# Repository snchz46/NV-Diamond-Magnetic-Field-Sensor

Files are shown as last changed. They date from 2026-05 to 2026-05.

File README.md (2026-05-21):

# NV-Center Optical Readout System — Fraunhofer IAO

> Hardware and firmware platform for Nitrogen-Vacancy (NV) center-based optical sensing.
> Acquires photon-count signals from NV-center diamond samples, applies quenching pulses,
> and streams live data via a browser dashboard hosted on an ESP32-S3.




---

## System at a glance

<p align="left">
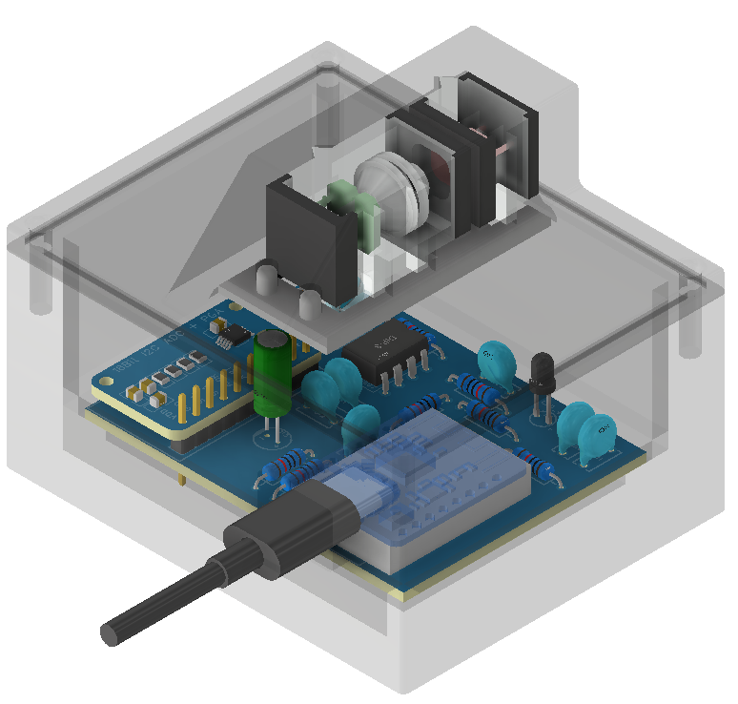
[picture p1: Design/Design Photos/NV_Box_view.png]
  
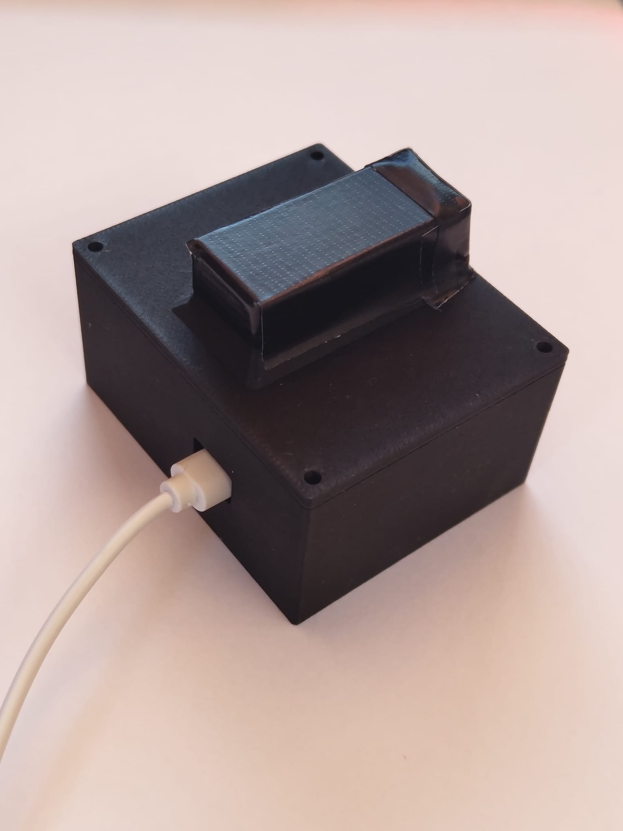
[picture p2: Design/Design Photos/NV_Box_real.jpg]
  
</p>

<!-- PLACEHOLDER: animated GIF or short demo video link
<p align="center">
  <a href="https://YOUR_VIDEO_LINK">
    <img src=""Design/Design Photos/web_dashboard_preview.gif" alt="Web dashboard demo" width="600"/>
  </a>
</p>
-->

<p align="left">
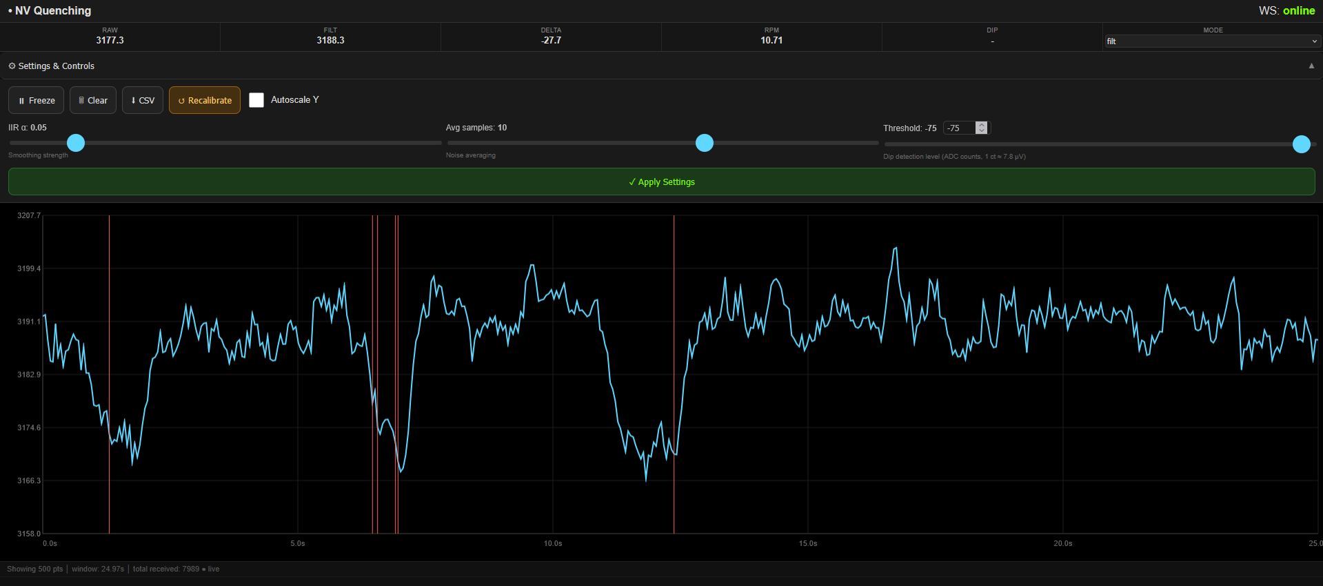
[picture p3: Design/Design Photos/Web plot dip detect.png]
ADC signal plot
  
</p>

---

## Module gallery

| NV Module | Optical Module | Quenching PCB |
|:---:|:---:|:---:|
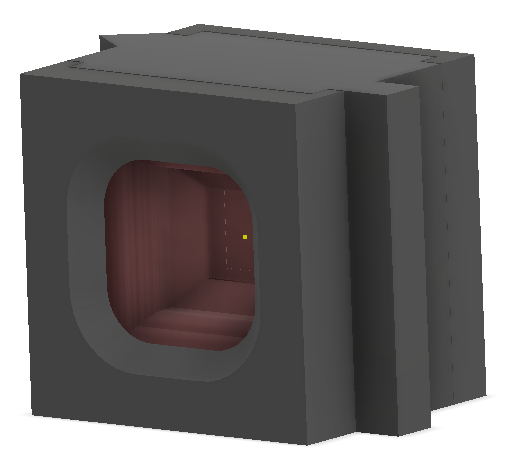
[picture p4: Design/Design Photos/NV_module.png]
NV Module
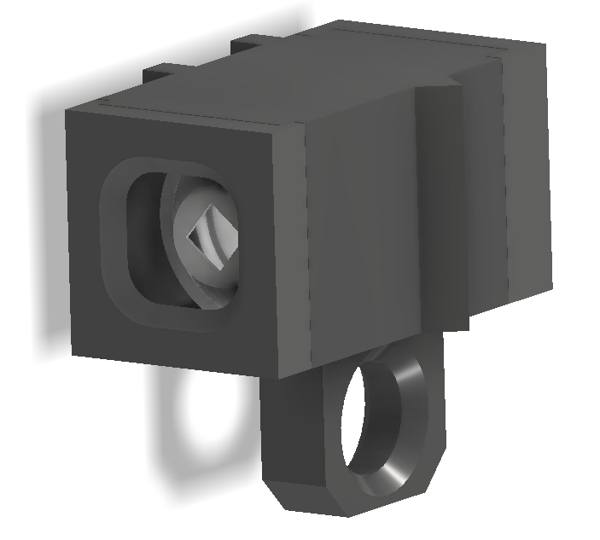
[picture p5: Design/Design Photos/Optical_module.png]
Optical Module
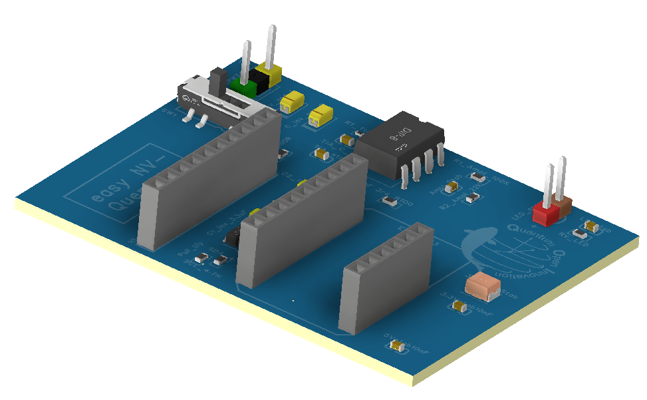
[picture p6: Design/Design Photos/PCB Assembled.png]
PCB
|  |  |  |
| Diamond sample holder | BPW34 photodetector | Rev-5 quenching board |

---

## Hardware overview

| Module | Description | Photo |
| --- | --- | ----- |
| **NV Module** | Diamond sample holder with optical coupling | <!-- PLACEHOLDER: `![](Design Photos/NV_module.png)` --> |
| **Optical Module** | BPW34 photodetector with signal conditioning | <!-- PLACEHOLDER: `![](Design Photos/Optical_module.png)` --> |
| **Quenching PCB (rev 5)** | Laser/MW pulse driver for spin initialization | <!-- PLACEHOLDER: `![](Design Photos/PCB Assembled.png)` --> |
| **Readout Box** | Enclosure integrating all modules | <!-- PLACEHOLDER: `![](Design Photos/NV_Box.png)` --> |
| **ESP32-S3** | Main MCU — ADC readout + Wi-Fi web server | |
| **ADS1015 / ADS1115** | External 12/16-bit ADC for precision readout | |

---

## Schematic

<p align="left">
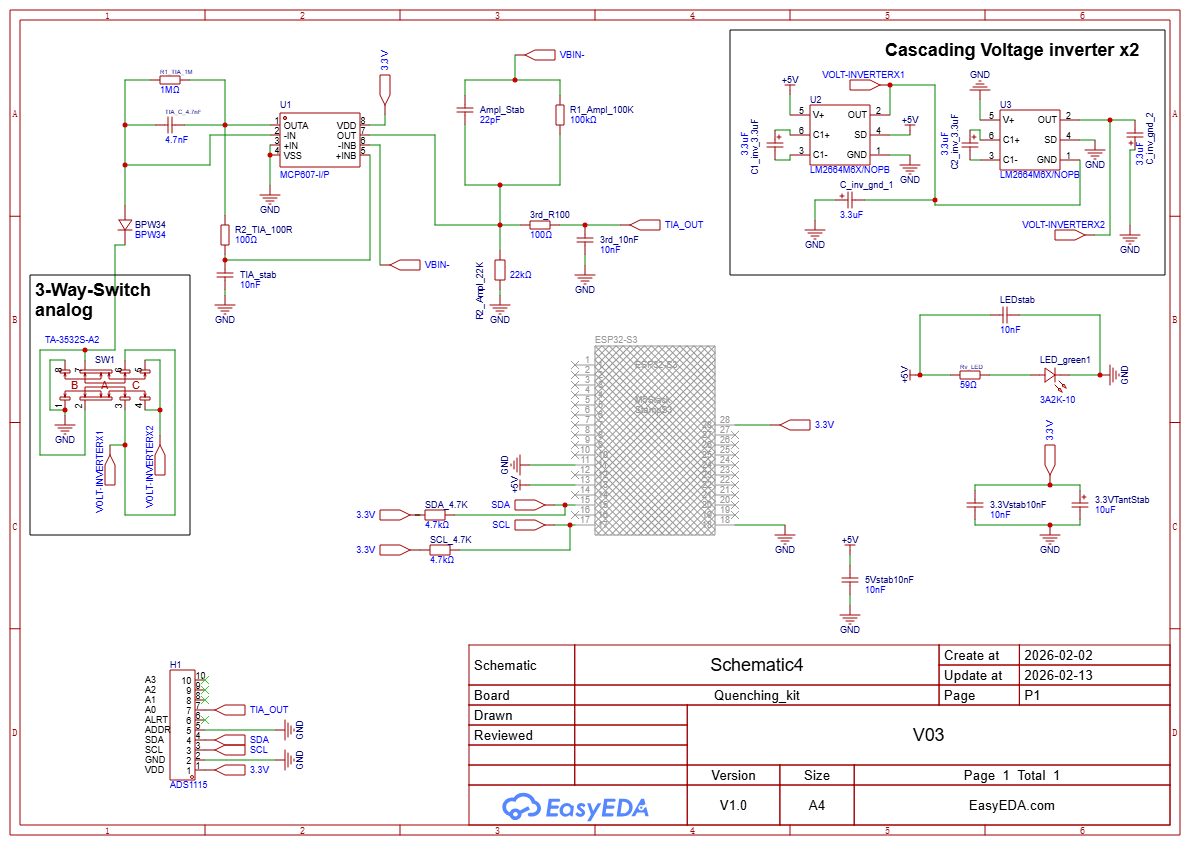
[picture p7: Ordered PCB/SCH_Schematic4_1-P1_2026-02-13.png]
Schematic rev 5
  
</p>

Full schematic PDF → [`SCH_Schematic4_2026-02-13.pdf`](Ordered%20PCB/SCH_Schematic4_2026-02-13.pdf)

---

## Performance results

| Metric | Value | Conditions |
| --- | ----- | --- |
| ADC noise floor | ___ LSB RMS | ADS1115, PGA ±0.256 V |
| Sampling rate | ___ Hz | Web server mode |
| Signal-to-noise ratio | ___ dB | Laser power: ___ mW |
| Quenching pulse width | ___ µs | |
| Web dashboard latency | ___ ms | LAN, single client |

<p align="left">
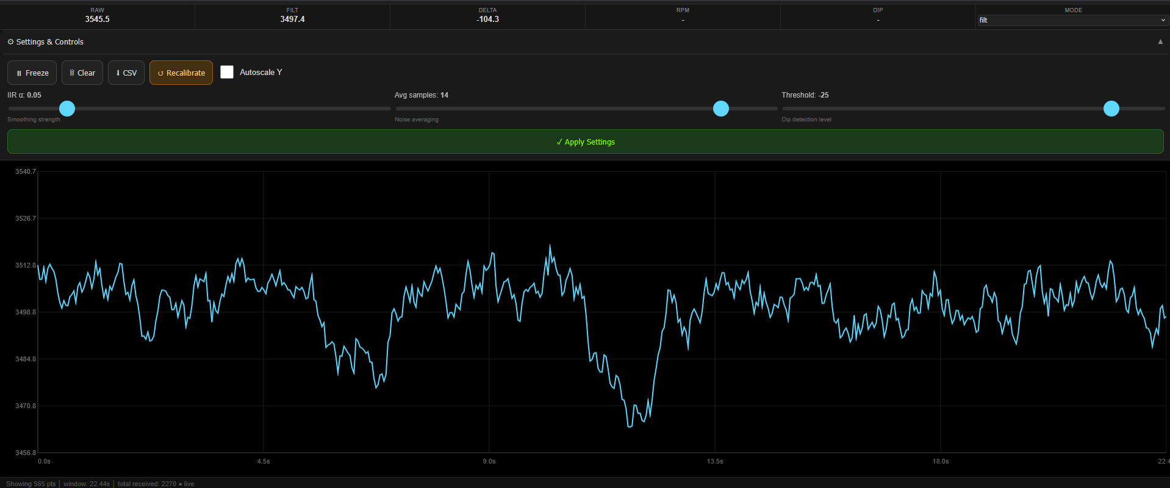
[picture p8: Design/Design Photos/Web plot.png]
Signal comparison
  
  <br><em>Figure 1 — Raw vs. optimized ADC readout (ADD CAPTION)</em>
</p>

---

## Assembly walkthrough

|  |  |
| - | - |
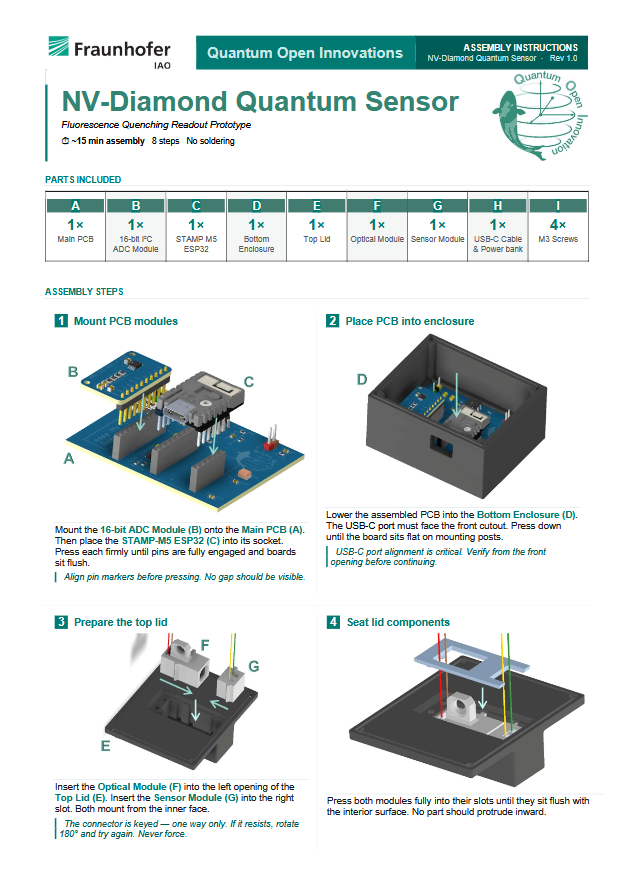
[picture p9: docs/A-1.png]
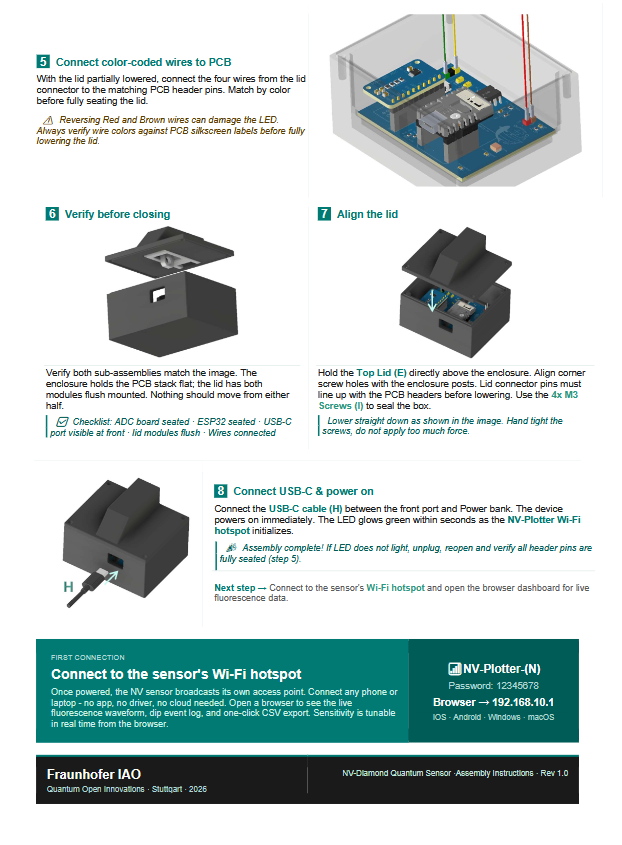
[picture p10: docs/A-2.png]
|  |  |

---

## Web dashboard

<p align="left">
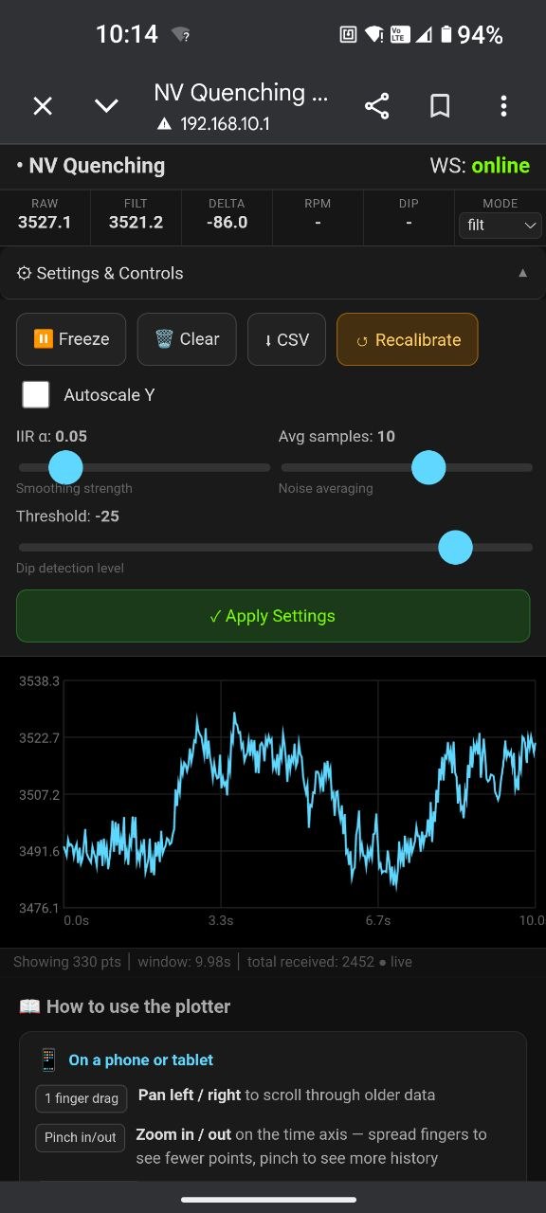
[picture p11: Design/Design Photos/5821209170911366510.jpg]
Live web dashboard
  
  <br><em>Live ADC readout served from ESP32-S3 over Wi-Fi</em>
</p>

After flashing, the ESP32 hosts a dashboard at the IP shown on the serial monitor:

- Live ADC signal plot
- Start / Stop acquisition
- CSV data export

---

## 3D model

<p align="left">
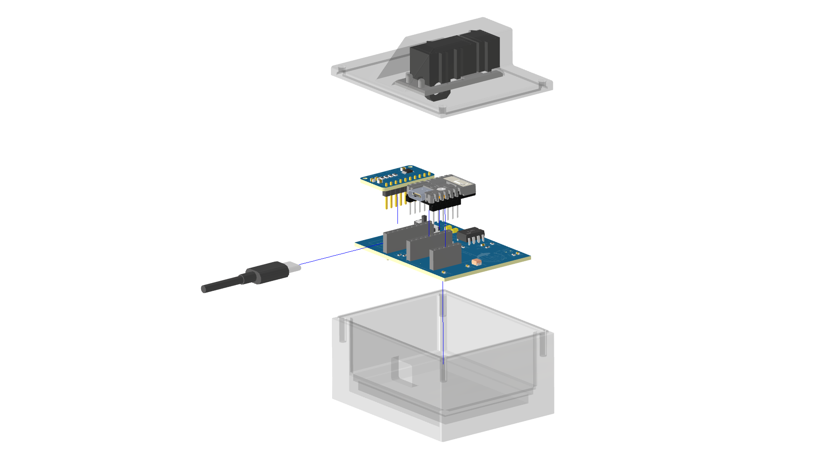
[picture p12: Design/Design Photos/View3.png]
3D assembly
  
</p>

CAD files: Autodesk Inventor assemblies in `Design/`. Printable STLs in `Design/Print/`.

---

## Project structure

```text
Fraunhofer/
├── Design/                        # Mechanical CAD (Autodesk Inventor)
│   ├── Parts/                     # Component libraries (PCB 3D models, connectors, sensors)
│   ├── Photos/                    # Renders and assembly photos
│   ├── Print/                     # 3D-printable STL exports
│   ├── Assembly_NV_Module.iam     # NV sensor module assembly
│   ├── Assembly_Optical_Module.iam
│   ├── Assembly_Quenching.iam
│   └── Assembly_Box.iam           # Enclosure assembly
│
├── Design Photos/                 # Step-by-step build photos and design plots
│
├── ESP32/                         # Firmware (PlatformIO / Arduino)
│   └── ReadOut/
│       ├── ESP32S3 ReadOut/                       # Base acquisition firmware
│       ├── ESP32S3 ReadOut Web Server/            # Web interface variant
│       ├── ESP32S3 ReadOut Web Server Optimized/  # Production variant
│       └── ESP32S3 Noise Optimization/            # ADC noise experiments
│
└── Ordered PCB/                   # Manufacturing files — PCB revision 5
    ├── Gerber_PCB5_2026-02-13.zip
    ├── BOM_Quenching_kit_PCB5_2026-02-13.xlsx
    ├── PickAndPlace_PCB5_2026-02-13.xlsx
    └── SCH_Schematic4_2026-02-13.pdf
```

---

## Firmware

Built with **PlatformIO** (Arduino framework).

```bash
cd "ESP32/ReadOut/ESP32S3 ReadOut Web Server Optimized"
pio run --target upload
```

---

## PCB manufacturing (rev 5)

| File | Purpose |
| ---- | --- |
| `Gerber_PCB5_2026-02-13.zip` | Upload to JLCPCB / PCBWay |
| `BOM_Quenching_kit_PCB5_2026-02-13.xlsx` | Bill of materials |
| `PickAndPlace_PCB5_2026-02-13.xlsx` | SMT assembly file |
| `SCH_Schematic4_2026-02-13.pdf` | Full schematic |
| `3D_PCB5.step` | 3D PCB model |

---

## Dependencies

| Tool | Version |
| ---- | --- |
| Autodesk Inventor | 2024+ |
| PlatformIO | Latest (VS Code extension) |
| EasyEDA | v6.5.51 |
| ESP32 Arduino core | Latest stable |

---

## Authors

Samuel Sanchez Moreno — Fraunhofer IAO (HiWi, 2025–2026)

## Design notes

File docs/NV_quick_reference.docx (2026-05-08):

NV Quenching Readout System

Quick Reference — Firmware & Software

Samuel Sanchez | Fraunhofer IAO, Quantum Open Innovations | 2025

# At a Glance

16-bit ADC resolution | 7.8 µV/LSB At GAIN_SIXTEEN | 0.34 mV RMS System noise | 2–3 % Quench amplitude

~86 Hz Step rate | ~22 Hz WebSocket rate | ~91 s CSV buffer | < 20 € Total BOM cost

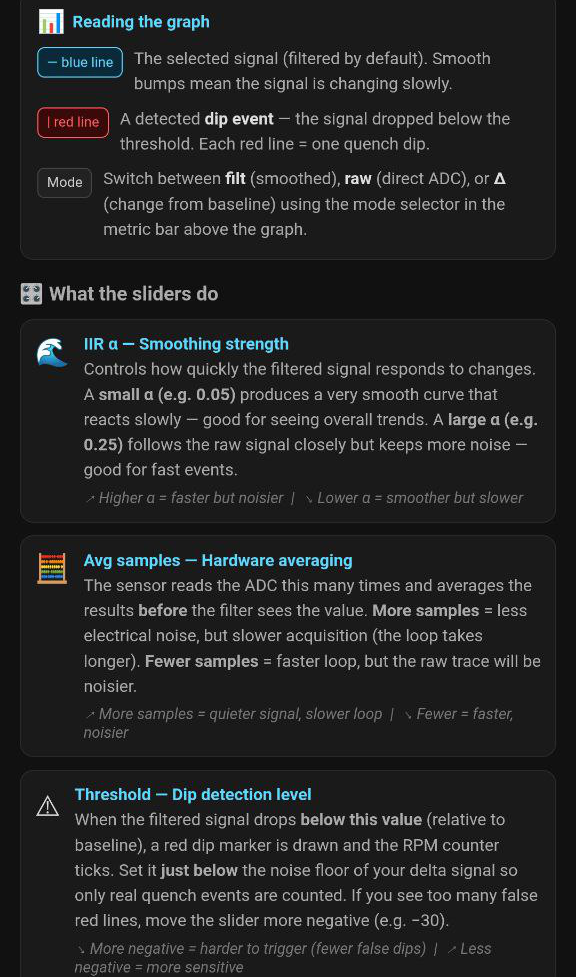
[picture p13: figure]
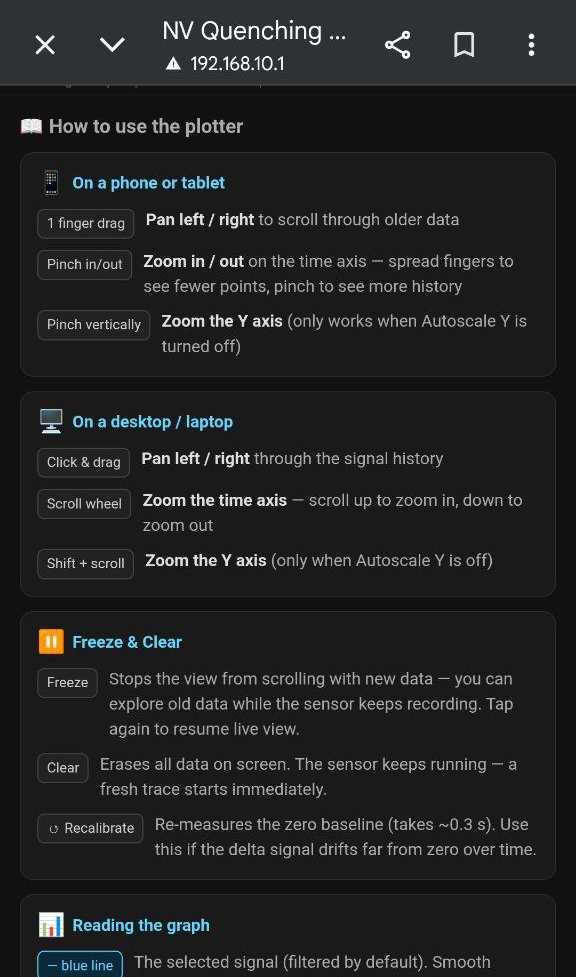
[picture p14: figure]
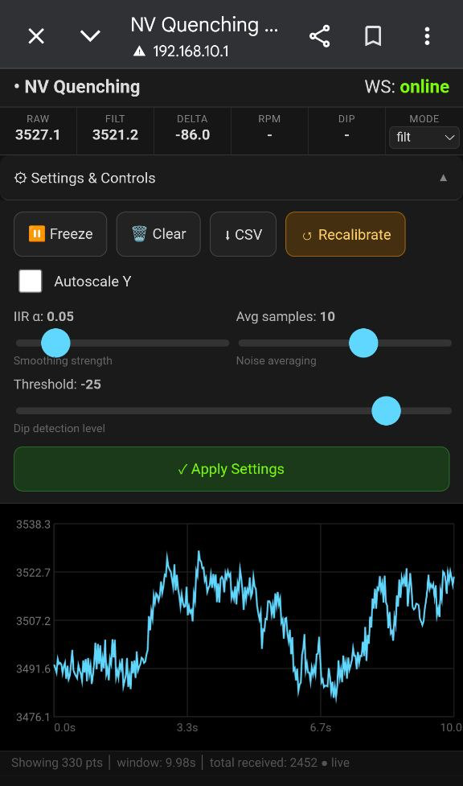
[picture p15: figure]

Figure 1 Live interface with built in settings panel and usage guide

# System Overview

Hardware chain - BPW34 photodiode — light-to-current - MCP607 TIA — Rf = 1 MΩ, 0–1 V output - RC filter — 2-stage, fc ≈ 160 kHz - ADS1115 — 16-bit I²C ADC, 860 SPS - ESP32-S3 — M5 Stamp S3, Wi-Fi AP Connectivity - Wi-Fi AP — SSID: NV-Plotter-N - IP — 192.168.10.1 - mDNS — http://nv-plotter.local - HTTP :80 — browser app + CSV export - WebSocket :81 — live data + config | Signal path - Average N fresh ADC reads - Display IIR filter — slow (α configurable) - Detection IIR filter — fast (α = 0.50, fixed) - Baseline subtraction — delta = filtered − baseline - Hysteresis comparator — entry + 50 ms guard - Dip latch — accumulates over 4-step window - Publish JSON — ~22 Hz to all WS clients - CSV ring buffer — 2000 entries, ~91 s Firmware modules - nv_signal — ADC, filters, dip, RPM - csv_logger — buffer + HTTP export - web_ui — AP, HTTP, WebSocket - web_page — full browser app (PROGMEM) - main — loop, decimation, latch

# System Performance

Parameter | Value | Notes
ADC resolution | 16-bit (7.8 µV/LSB) | GAIN_SIXTEEN, ±0.256 V FS
Noise single read | ~2 LSB RMS ≈ 15.6 µV | ADS1115 datasheet at 860 SPS
Noise avg = 10 | ~0.6 LSB RMS ≈ 4.7 µV | √10 improvement
System noise (measured) | 0.34 mV RMS | At TIA output
Baseline signal level | 0.80–1.00 V | 525-532 nm LED, BPW34, Rf = 1 MΩ
Quench dip amplitude | 15–30 mV (2–3%) | 1920-3840 ADC counts
Display filter −3 dB | ~0.69 Hz | α = 0.05, ~86 steps/s
Detection filter −3 dB | ~21 Hz | α = 0.50, ~86 steps/s
Step rate | ~86 steps/s | 860 SPS / avg = 10
WebSocket rate | ~22 Hz | Step rate / SEND_EVERY_N = 4
CSV buffer | 2000 samples (~91 s) | Static allocation, ~56 KB RAM
Max dip rate | 1200 dips/min | MIN_DIP_INTERVAL_MS = 50 ms
Encoder — mean RPM | 61.5 rpm (±3.9 rpm, 6.3%) | 6 dips; theoretical 58.6 rpm
Encoder — deviation | +4.9 % | SG90 servo dynamics, not ADC error
Total BOM cost | ~20 € | Including ADS1115 and Fabricated PCB

# Configuration Parameters

## Run-time (adjustable from browser, no reflash)

Parameter | Default | Range | Unit | Effect
IIR α — display filter | 0.05 | 0.01–0.50 | — | Displayed trace smoothness. No effect on dip detection.
Averaging depth | 10 | 1–32 | samples | Noise reduction (√N). Adds N × 1.16 ms latency per step.
Detection threshold | −15 | −5000–0 | ADC cts | Dip trigger level. 1 ct ≈ 7.8 µV. Set to ~50% of dip depth.

## Compile-time (edit source, reflash)

Constant | File | Default | Description
SEND_EVERY_N | main.cpp | 4 | Decimation ratio. 1 of N steps forwarded to WS and CSV.
RPM_HIST | nv_signal.cpp | 8 | Inter-dip interval ring buffer depth. Larger = smoother RPM.
MIN_DIP_INTERVAL_MS | nv_signal.cpp | 50 ms | Dead time between dip entries. 50 ms ↔ max 1200 dips/min.
DETECT_ALPHA | nv_signal.cpp | 0.50 | Detection filter α. Fixed — do not reduce below 0.30.
CSV_BUF_N | csv_logger.cpp | 2000 | Ring buffer capacity. Each entry ≈ 28 bytes.

Threshold calibration

1. Set Mode to Δ.

2. Approach the magnet and read the minimum delta in the metric strip.

3. Set threshold to ~50% of that minimum.

Example: delta reaches −80 → set threshold to −40.

4. Press Apply Settings. Confirm red dip markers appear on approach.

# Main Features

Signal Processing - Dual IIR filters — independent display and detection paths - Paced averaging — N distinct conversions per step - Static baseline — 60-sample average at startup - Live recalibration — /recal HTTP or browser button - Hysteresis comparator — 50% exit threshold - Dip guard timer — prevents burst false triggers - RPM averaging — 8-interval ring buffer - Angular velocity & accel. — ω and α computed per dip Data Export - CSV download — /export.csv, chunked HTTP - Relative timestamps — seconds from oldest sample - Columns — t_s, raw, filtered, delta, dip, rpm - Auto filename — nv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 | Browser Interface - Zero dependencies — served from ESP32 flash (PROGMEM) - Live metric strip — raw, filt, Δ, RPM, dip, mode - 5000-point ring buffer — typed arrays, no GC pressure - 60 fps canvas render — signal trace + dip markers - HiDPI aware — crisp on Retina / AMOLED - Mobile responsive — adaptive layout below 420 px - Freeze / Clear — view control without data loss - Autoscale Y — or manual zoom via pinch / Shift+scroll Interaction Gestures - 1-finger drag — pan time axis - 2-finger pinch (H) — zoom time axis - 2-finger pinch (V) — zoom Y axis - Mouse drag — pan - Scroll wheel — zoom 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

# HTTP & WebSocket Quick Reference

Endpoint | Method | Description
192.168.10.1 or nv-plotter.local | GET | Browser application (HTML/CSS/JS, ~12 KB, no CDN)
/export.csv | GET | Download full ring buffer as CSV (chunked, nv_export.csv)
/recal | GET | Re-run 60-sample baseline capture; broadcasts recal_done to all WS clients
ws://192.168.10.1:81/ | WebSocket | Live data stream at ~22 Hz; accepts cfg messages; replies cfg_ack

## WebSocket messages

Server → Client (sample, ~22 Hz) { "t": 45231, // ms from boot "raw": 18432.5, // avg ADC counts "filtered": 18431.1, // display IIR "delta": -42.3, // counts vs baseline "dip": 1, // 1 on entry only "rpm": 61.5 } | Client → Server (config update) { "type": "cfg", "alpha": 0.05, "avg": 10, "thr": -45.0 } Server → Client (ack / recal) { "type": "cfg_ack", "alpha": 0.050, "avg": 10, "thr": -45.00 } { "type": "recal_done" }

# Build & Connect

platformio.ini [env:m5stack-stamps3] platform = espressif32@>=6 board = m5stack-stamps3 framework = arduino lib_deps = adafruit/Adafruit ADS1X15@^2.6.0 Flash command pio run --target upload | First-use steps 1. Connect to Wi-Fi: NV-Plotter-2 / 12345678 2. Open: http://nv-plotter.local 3. Observe live delta in the metric strip 4. Approach magnet → note minimum delta 5. Set threshold to ~50% of that value → Apply 6. Confirm red dip markers on approach 7. Recalibrate if delta drifts from zero

Fraunhofer IAO — Quantum Open Innovations | Samuel Sanchez | 1 / 2

NV Quenching Readout — Quick Reference

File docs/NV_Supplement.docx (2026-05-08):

Fraunhofer IAO

Firmware & Software Documentation

Suplement to: NV_Samuel_Report

Samuel Sanchez

2-19-2026

# Introduction

This document provides the technical reference for the embedded firmware and browser-based visualization software of the NV-diamond fluorescence quenching readout prototype. It describes the final implemented system: the signal-processing architecture, module responsibilities, configurable parameters, data structures, communication protocol, and measured performance.

The system runs on an M5 Stamp S3 (ESP32-S3) microcontroller. It acquires raw photodiode counts from a transimpedance amplifier (TIA) connected to a BPW34 photodiode, applies real-time digital filtering and baseline subtraction, detects fluorescence quenching dip events caused by an external magnetic field, estimates rotational parameters (RPM, angular velocity, angular acceleration), streams live data to a browser over Wi-Fi, and provides timestamped CSV export for offline analysis.

# System Architecture

## Module Overview

The firmware is structured as five independent modules with clearly separate responsibilities. This structure allows signal-processing parameters to be tuned independently of the communication layer.

File | Responsibility | Key Dependencies
nv_signal.cpp / .h | ADC acquisition, IIR filtering, baseline subtraction, dip detection, RPM estimation | Adafruit ADS1X15, Wire (I²C)
csv_logger.cpp / .h | Circular sample buffer; chunked HTTP CSV export with relative-second timestamps | WebServer
web_ui.cpp / .h | Wi-Fi Access Point, HTTP server (port 80), WebSocket server (port 81), configuration handler | WiFi, WebServer, WebSocketsServer, ESPmDNS
web_page.cpp / .h | Complete single-page browser application stored in flash (PROGMEM); served as a static string | None (self-contained)
main.cpp | Main acquisition loop; dip event accumulation across the decimation window; sample forwarding to logger and WebSocket | All modules

## Signal Path — From Photon to Browser

The table below traces the complete measurement chain from the photodiode to the rendered waveform in the browser, identifying the location and nature of each transformation.

Stage | Location | Operation | Output
Photon → Current | BPW34 photodiode | Light-to-current conversion | i⁐⁄ (nA–µA)
Current → Voltage | MCP607 TIA (Rf = 1 MΩ) | Transimpedance gain | Vₜᴵᴬ (0–1 V typ.)
Anti-alias filtering | RC network (100 Ω, 10 nF ×2) | 2-stage passive low-pass, f⁣ ≈ 160 kHz | Filtered analogue voltage
Digitisation | ADS1115, GAIN_SIXTEEN, 860 SPS | 16-bit ADC; 1 LSB = 7.8125 µV at ±0.256 V FS | Raw counts (int16_t)
Hardware averaging | nv_step() — readOneFreshConversion() | N distinct conversions summed and divided; paced at the ADC conversion period | rawAvg (float counts)
Display IIR filter | nv_step(), configurable α | filteredRaw += α·(rawAvg − filteredRaw) | filteredRaw (float)
Detection IIR filter | nv_step(), fixed α = 0.50 | detectedFiltered += 0.50·(rawAvg − detectedFiltered) | detectedFiltered (float)
Baseline subtraction | nv_step() | delta = filteredRaw − baseline | delta (float counts)
Dip detection | nv_step() — hysteresis comparator | Entry if detectionDelta < threshold and inter-dip guard satisfied | dipEvent (bool), RPM (float)
Decimation & latch | loop() in main.cpp | Accumulate dipEvent flag over 4 steps; forward one sample per 4 steps | Latched NvSample
WebSocket publish | web_publish_sample() | JSON frame broadcast to all clients at ~22 Hz | JSON string (~200 B)
CSV logging | csv_push() | Write to 2000-entry circular ring buffer | Ring buffer entry
Browser rendering | JavaScript canvas loop | 5000-point ring buffer; 60 fps canvas draw; pan and pinch-zoom | Live waveform display

# Module Reference

## nv_signal — Signal Acquisition and Processing

This module is the scientific core of the firmware. Every decision that affects measurement fidelity — ADC gain, averaging depth, filter bandwidth, detection sensitivity, and RPM accuracy — is implemented and encapsulated here. The public API consists of five functions: nv_init(), nv_recalibrate(), nv_step(), nv_get_config(), and nv_set_config().

### ADS1115 Configuration

Gain: GAIN_SIXTEEN — full-scale range ±0.256 V, 1 LSB = 7.8125 µV. Chosen to maximise resolution for the small TIA output variations (15–30 mV) that correspond to 2–3% fluorescence quenching. The gain setting keeps the expected baseline voltage of ~0.5 V well within the input range.

Data rate: RATE_ADS1115_860SPS — the highest available rate, giving one conversion every ≈1163 µs. The faster rate is compensated by the averaging stage.

Conversion mode: Continuous (startADCReading, continuous = true). The ADC free-runs and always presents the most recent result in its output register, which is read non-blocking via getLastConversionResults().

### Baseline Capture

The baseline is captured once at startup and can be refreshed at any time by calling nv_recalibrate() — available via the browser Recalibrate button or the /recal HTTP endpoint — without rebooting the device. The capture procedure:

1. Discard 10 warm-up conversions at the paced rate to allow the ADC reference and TIA output to settle.
2. Accumulate 60 consecutive fresh conversions (~70 ms total); compute their arithmetic mean as the static baseline.
3. Initialise both IIR filter states (filteredRaw and detectedFiltered) to the baseline value to prevent transient false events on the first acquisition steps.
4. Reset all dip-detection state: dipState = false, lastDipTimeMs = 0, RPM history cleared to zero.

Baseline stability

The baseline is a static scalar. Slow thermal drift of the TIA or gradual LED power changes will cause the delta signal to walk from zero over time. If this is observed, pressing Recalibrate in the browser re-runs the 70 ms capture procedure and updates all filter states without interrupting the Wi-Fi connection.

### Hardware Averaging

nv_step() averages samplesToAvg distinct ADC conversions per processing step. Each read is paced to the ADS1115 conversion period so that every call to readOneFreshConversion() retrieves a genuinely new result. The pacing function compares the elapsed microseconds since the last read against CONV_PERIOD_US (1163 µs at 860 SPS) and inserts a brief wait if needed.

nv_signal.cpp — readOneFreshConversion()

static inline int16_t readOneFreshConversion() {

static unsigned long lastReadUs = 0;

unsigned long now = micros();

if (now - lastReadUs < CONV_PERIOD_US)

delayMicroseconds(CONV_PERIOD_US - (now - lastReadUs));

lastReadUs = micros();

return ads.getLastConversionResults();}

With samplesToAvg = 10 and GAIN_SIXTEEN, the theoretical noise reduction from averaging is √10 ≈ 3.16×, reducing effective input-referred noise from ~2 LSB RMS (ADS1115 datasheet) to ~0.6 LSB RMS ≈ 4.7 µV.

### Dual-Filter Architecture

Two independent first-order IIR low-pass filters operate on the same average raw signal. Their roles are strictly separated to decouple visual smoothness from detection responsiveness.

Filter | State variable | α | Time constant (τ) | Role
Display filter | filteredRaw | Configurable 0.01–0.50 | ≈1/α steps | Produces the smooth waveform rendered in the browser. Default α = 0.05 gives τ ≈ 20 steps (≈0.23 s at 86 steps/s). Not used for threshold decisions.
Detection filter | detectedFiltered | Fixed 0.50 | ≈2 steps | Tracks sharp dip edges fast enough to follow real quench events. Feeds the threshold comparator and hysteresis exit test exclusively.

The IIR update equation for both filters is identical in form:

y[n] = y[n−1] + α · (x[n] − y[n−1])

where x[n] is the current averaged raw count and y[n] is the filter output. For the display filter with α = 0.05 and a step rate of ~86 Hz, the −3 dB cut-off frequency is approximately f⁣ = α·f_step / (2π) ≈ 0.69 Hz.

### Dip Detection

Dip detection uses a two-threshold (hysteresis) state machine operating on the fast detection filter output. The detection delta is defined as detectionDelta = detectedFiltered − baseline.

Transition | Condition | Guard
Armed → Dip | detectionDelta < DIP_THRESHOLD | Minimum inter-dip interval of 50 ms must have elapsed since the previous confirmed dip (prevents burst re-triggering near the exit hysteresis).
Dip → Armed | detectionDelta > DIP_THRESHOLD × 0.5 | None — exit is immediate once the fast filter recovers above the hysteresis level.

On each Dip entry: dipEvent is set to true for that single step, and computeRpm() is called with the current millisecond timestamp. The 50 ms minimum inter-dip guard (MIN_DIP_INTERVAL_MS) corresponds to a maximum detectable dip rate of 1200 events per minute, well above any rotation speed tested with the prototype.

nv_signal.cpp — threshold comparator in nv_step()

if (!dipState

&& detectionDelta < DIP_THRESHOLD

&& (lastDipTimeMs == 0 ||

(now - lastDipTimeMs) >= MIN_DIP_INTERVAL_MS)) {

dipState = true; dipEvent = true;

computeRpm(now);}

if (dipState && detectionDelta > DIP_THRESHOLD * 0.5f)

dipState = false;}

### RPM and Angular Velocity

Each confirmed dip entry records its millisecond timestamp. The inter-dip interval dt is stored in a circular ring buffer of depth RPM_HIST = 8. The mean of all stored intervals is used to compute RPM, smoothing out single-period timing jitter:

RPM = 60 000 / mean(dt₁, dt₂, …, dt₈)

Angular velocity is derived as ω = RPM × 2π / 60 (rad/s). Angular acceleration α = Δω / Δt (rad/s²) is computed between consecutive dip events and reported in the serial encoder output. These are the values listed in the Results section of the main report.

## csv_logger — Sample Buffer and CSV Export

csv_logger maintains a static circular buffer of 2000 NvSample entries allocated in BSS (zero-initialised, no heap allocation). Samples are written by csv_push() on every forwarded step. When the buffer is full, new entries overwrite the oldest.

Buffer parameter | Value | Notes
Capacity | 2000 samples | Static allocation — no heap fragmentation risk
Entry size | ~28 bytes | uint32_t + float×4 + bool + float
Total RAM used | ~56 KB | Well within the ESP32-S3's 520 KB SRAM
Write rate | ~22 Hz | 860 SPS / avg=10 / SEND_EVERY_N=4
Buffer duration | ~91 s | 2000 samples / 21.5 Hz

CSV export is delivered as a chunked HTTP response (CONTENT_LENGTH_UNKNOWN) so that the entire payload is never buffered in heap memory simultaneously. Rows are formatted and streamed one at a time with snprintf(). Timestamps are expressed as seconds elapsed from the oldest sample in the export window, making the data immediately plottable in any spreadsheet application.

csv_logger.cpp — relative timestamp conversion

uint32_t t0 = buf[start % CSV_BUF_N].t_ms; // oldest entry

float t_s = (float)(s.t_ms - t0) / 1000.0f; // seconds from start

The CSV column order is: t_s, raw, filtered, delta, dip (0 or 1), rpm. A Content-Disposition header is included so that browsers automatically suggest the filename nv_export.csv on download.

## web_ui — Wi-Fi, HTTP, and WebSocket Server

The ESP32-S3 operates as a Wi-Fi Access Point (SSID: NV-Plotter-N, password: 12345678) with a fixed IP address of 192.168.10.1. This removes any dependency on laboratory network infrastructure and allows direct connection from a smartphone or laptop without router access. mDNS is advertised under the hostname nv-plotter, enabling connection via http://nv-plotter.local.

Endpoint | Protocol | Description
GET / | HTTP port 80 | Serves the complete browser application from PROGMEM. Cache-Control: no-store prevents stale caching across firmware updates.
GET /export.csv | HTTP port 80 | Triggers chunked CSV streaming of the 2000-entry ring buffer. Content-Disposition header set for automatic browser download.
GET /recal | HTTP port 80 | Executes nv_recalibrate() (~70 ms), then broadcasts {"type":"recal_done"} to all connected WebSocket clients. Returns 200 OK.
WS port 81 | WebSocket | Bidirectional channel. Server pushes JSON sample frames at ~22 Hz. Client sends configuration updates; server replies with clamped values. See Appendix B for the full message protocol.

Configuration messages received via WebSocket are parsed by extractNumber(), a minimal hand-written function that locates a named key and reads the following numeric token. This avoids the overhead of a general-purpose JSON library (ArduinoJson) while remaining sufficient for the fixed, schema-controlled message format.

## web_page — Browser Application

The complete user interface is stored as a C string constant in the ESP32's flash (PROGMEM) and served on demand. It requires no internet connection, no CDN, and no external dependencies. The HTML, CSS, and JavaScript fit within approximately 12 KB.

### Metric Strip and Settings Panel

On load, a six-cell metric strip at the top of the page shows live values for raw ADC count, filtered ADC count, delta (baseline-subtracted), RPM, dip indicator, and the active display mode selector. Below it, a full-width settings panel is open by default, exposing all three configurable signal-processing parameters as range sliders with companion labels and a numeric text input for precise threshold entry.

### Client-Side Data Buffer

The browser maintains a ring buffer of 5000 points using three typed arrays: Float64Array for timestamps, Float32Array for signal values, and Uint8Array for dip flags. Typed arrays are used deliberately — they are contiguous in memory and avoid garbage-collector pressure during the 60 fps draw loop. The ring buffer correctly handles the wrap-around index mapping in both the partially filled and fully overwritten states.

### Canvas Rendering

- HiDPI support: the canvas pixel buffer is allocated at cssW × devicePixelRatio. ctx.setTransform(dpr, 0, 0, dpr, 0, 0) scales all draw calls to CSS-pixel coordinates, producing a sharp trace on Retina and high-DPI AMOLED displays without changing any rendering logic.
- Adaptive layout: on screens narrower than 420 px, Y-axis margin narrows from 62 px to 48 px, Y-tick count reduces from 6 to 4, and X-tick count from 5 to 3 — maintaining readability on 375 px portrait phone screens.
- Signal trace: drawn as a continuous polyline in cyan (#5fd7ff) at 2 px width (1.5 px on narrow screens).
- Dip markers: each sample with dip = 1 produces a full-height vertical red line at the corresponding X position. Markers are rendered in a second pass after the signal trace to guarantee visibility.
- Frozen mode: when active, the view stops following new data. A translucent amber overlay and FROZEN label are drawn over the plot. New data continues to accumulate in the ring buffer so no samples are lost.
- Autoscale Y: when checked, the Y axis range recomputes on every frame from the visible window's min/max, with 15% padding. When unchecked, the manual yCenter and ySpan values are used, adjustable by Shift+scroll or vertical pinch.

### Interaction Gestures

Input | Device | Action
1-finger drag | Touch | Pan the time axis — viewEnd shifts by dx × (viewSpan / cssW) logical points
2-finger horizontal pinch | Touch | Zoom the time axis, anchored at the midpoint between the two contact points
2-finger vertical pinch | Touch | Zoom the Y axis (only when Autoscale Y is disabled)
Click and drag | Mouse | Pan — identical formula to 1-finger drag
Scroll wheel | Mouse | Zoom the time axis, anchored at the cursor X position
Shift + scroll wheel | Mouse | Zoom the Y axis (only when Autoscale Y is disabled)

Touch events are tracked by pointer identifier in an activeTouches dictionary. Horizontal versus vertical pinch is determined by comparing |dx| and |dy| between the two contact points: horizontal dominance routes to time-axis zoom; vertical dominance routes to Y-axis zoom.

### User Instructions Panel

A permanent instructions section below the plot describes all gestures, button functions, and slider effects in plain language accessible to users ranging from high-school students to research engineers. It includes a dedicated threshold calibration procedure and explains the unit convention (ADC counts, 1 count ≈ 7.8 µV at GAIN_SIXTEEN).

## main — Acquisition Loop and Dip Accumulation

The main loop calls nv_step() on every iteration. One out of every SEND_EVERY_N = 4 steps is forwarded to the WebSocket publisher and CSV logger, reducing network traffic to ~22 Hz.

Because NvSample.dip is a single-shot pulse — true for exactly the one step where the detection threshold is first crossed — a static accumulation latch (dipPending) ensures that a dip event occurring on any of the 4 steps in a decimation window is reliably carried through to the forwarded sample.

main.cpp — acquisition loop with dip accumulation latch

static bool dipPending = false;

void loop() {

web_loop();

NvSample s = nv_step();

if (s.dip) dipPending = true;

if (++counter % SEND_EVERY_N == 0) {

s.dip = dipPending;

dipPending = false;

csv_push(s);

web_publish_sample(s.raw, s.filtered, s.delta, s.dip, s.rpm);

}

}

# Configuration Parameters

Three parameters can be adjusted at run-time from the browser settings panel without reflashing. Changes are applied immediately on pressing Apply Settings; the WebSocket cfg_ack response confirms the values in use after internal clamping.

Parameter | Default | Range | Unit | Effect
IIR α (display filter smoothing) | 0.05 | 0.01–0.50 | — | Bandwidth of the displayed trace. Lower α = smoother, slower-responding curve. Higher α = closer to raw signal, more visible noise. Does not affect dip detection.
Averaging depth | 10 | 1–32 | samples | Number of distinct ADC conversions averaged per processing step. Improves input-referred noise by √N. Also increases step latency by N × 1163 µs.
Detection threshold | −15 | −5000 to 0 | ADC counts | Level that detectionDelta must fall below to register a dip. 1 count = 7.8125 µV at GAIN_SIXTEEN. Adjustable via slider (step 5) or direct numeric entry.

Threshold calibration

1. Set the Mode selector to Δ (delta).

2. Perform a magnet approach while observing the delta value in the metric strip.

3. Note the minimum (most negative) delta reached during the dip.

4. Set the threshold to approximately 50–60 % of that minimum.

Example: if delta reaches −80 counts, set threshold to −40 to −48 and press Apply Settings.

5. Confirm that red dip markers appear on subsequent approaches and disappear on removal.

Three additional parameters are compile-time constants in the source files:

Constant | File | Default | Description
SEND_EVERY_N | main.cpp | 4 | Decimation ratio. Every Nth step is forwarded to WebSocket and CSV. Adjust to trade off temporal resolution against network load.
RPM_HIST | nv_signal.cpp | 8 | Depth of the inter-dip interval ring buffer. Larger values give smoother RPM at the cost of slower response to genuine speed changes.
MIN_DIP_INTERVAL_MS | nv_signal.cpp | 50 ms | Minimum time between consecutive dip entries. Prevents burst false-triggers near the hysteresis exit level. 50 ms ↔ max 1200 dips/min.

# Data Structures

## NvSample

NvSample is the fundamental unit of data passed between all modules. It is populated by nv_step(), written to the CSV ring buffer, and serialised to JSON for WebSocket transmission.

nv_signal.h — NvSample

struct NvSample {

uint32_t t_ms; // millis() timestamp at end of step

float raw; // averaged raw ADC count (pre-filter)

float filtered; // display IIR output (slow, α configurable)

float delta; // filtered − baseline (ADC counts)

bool dip; // true on dip ENTRY only (single-shot pulse)

float rpm; // moving-average RPM from last 8 inter-dip intervals

};

## NvConfig

NvConfig carries the three run-time configurable parameters between the WebSocket handler and the signal processing module.

nv_signal.h — NvConfig

struct NvConfig {

float alpha; // display IIR smoothing factor

uint16_t avg; // number of fresh ADC conversions to average

float thr; // dip detection threshold (negative ADC counts)

};

# System Performance

The table below consolidates measured and theoretical performance figures of the complete acquisition and detection chain as validated in the final prototype evaluation.

Parameter | Value | Condition
ADC resolution | 16-bit (7.8125 µV/LSB) | ADS1115, GAIN_SIXTEEN (±0.256 V FS)
Single-read noise (typ.) | ~2 LSB RMS ≈ 15.6 µV | ADS1115 datasheet at 860 SPS
Noise with avg = 10 | ~0.6 LSB RMS ≈ 4.7 µV | √10 improvement from averaging
Measured system noise | 0.34 mV RMS | At TIA output; dominated by optical and TIA noise, not ADC
Baseline signal level | 0.80–1.00 V | Typical with 525–532 nm LED, BPW34, Rf = 1 MΩ
Quenching dip amplitude | 15–30 mV (2–3%) | 1920–3840 ADC counts at GAIN_SIXTEEN
Display filter – 3 dB | ≈0.69 Hz | α = 0.05, step rate ~86 Hz
Detection filter – 3 dB | ≈21 Hz | α = 0.50, step rate ~86 Hz
Step rate | ~86 steps/s | 860 SPS / avg = 10
WebSocket publish rate | ~22 Hz | Step rate / SEND_EVERY_N = 4
CSV buffer duration | ~91 s | 2000 entries at 22 Hz
Max detectable dip rate | 1200 dips/min | Limited by MIN_DIP_INTERVAL_MS = 50 ms
Encoder accuracy (mean RPM) | 61.5 rpm (±3.9 rpm, ~6.3%) | 6 consecutive dips; theoretical 58.6 rpm
Deviation from theoretical | +4.9% | Dominated by SG90 servo mechanical dynamics
Total system cost | ~9–16 € | Full BOM including ADS1115 external ADC

Encoder accuracy context

The 6.3 % standard deviation in RPM measurements is consistent with the known mechanical behaviour of the SG90 servo: the programmed step/delay pattern (15° per step, 1 ms delay, 500 ms endpoint dwell) produces a theoretical period of 1.024 s (58.6 rpm), but the servo’s internal dynamics cause actual motion to deviate from the commanded profile. The NV-based encoder faithfully captures the real mechanical motion rather than the ideal script.

# Build Environment and Deployment

## PlatformIO Configuration

platformio.ini

[env:m5stack-stamps3]

platform = espressif32@>=6

board = m5stack-stamps3

framework = arduino

upload_speed = 921600

upload_protocol = esptool

build_flags = -DARDUINO_USB_CDC_ON_BOOT=1 -std=gnu++17 -Wall

monitor_speed = 115200

lib_deps = adafruit/Adafruit ADS1X15@^2.6.0

## Library Dependencies

Library | Source | Purpose
Adafruit ADS1X15 v2.6.0+ | PlatformIO registry | ADS1115 driver: gain, data rate, continuous mode, getLastConversionResults()
WebServer | ESP-IDF built-in | HTTP server with chunked transfer and custom header support
WebSocketsServer | Links2004/arduinoWebSockets (auto-resolved by PIO) | WebSocket server on port 81 with broadcast support
ESPmDNS | ESP-IDF built-in | mDNS hostname advertisement (nv-plotter.local)
Wire | ESP-IDF built-in | I²C master interface for ADS1115

## First-Use Procedure

- Connect the M5 Stamp S3 via USB-C and flash with: pio run --target upload
- Connect a Wi-Fi client (phone or laptop) to the access point NV-Plotter-N, password 12345678
- Open a browser and navigate to http://192.168.10.1 or http://nv-plotter.local.
- The Settings panel opens automatically. Observe the live delta value in the metric strip.
- Perform a magnet approach and note the minimum delta count reached during the dip.
- Set the threshold to ~50 % of that minimum value and press Apply Settings.
- Confirm that red dip markers appear during subsequent magnet approaches. RPM populates after two consecutive confirmed dips.
- Use the Recalibrate button if the delta signal drifts far from zero in the absence of a magnet.

# Limitations and Recommended Future Work

## Static Baseline

The baseline is a single scalar captured at startup or on explicit recalibration. Slow thermal drift of the TIA or LED power decay will cause the delta signal to shift over time. A tracking baseline using a second, very slow IIR (α ≈ 0.0001) would compensate automatically, with care taken to prevent it from tracking the dip signal itself during magnet approach.

## First-Order Display Filter

The display IIR is a single-pole filter. For applications requiring a sharper transition between passband and stopband, a second-order Biquad IIR or a short FIR of approximately 20 taps could be implemented within the ESP32-S3 compute budget without affecting acquisition rate.

## Blocking Acquisition Loop

The readOneFreshConversion() pacing introduces a blocking delay of N × 1163 µs per step (~11.6 ms for avg = 10). During this period web_loop() is not called, which can delay WebSocket heartbeats at high averaging depths. Restructuring acquisition as a non-blocking state machine that yields to web_loop() between reads would eliminate this constraint.

## Access Point Mode Only

The sensor operates exclusively as a Wi-Fi Access Point. Adding optional Station (STA) mode would allow the device to join an existing network and forward data to remote servers or laboratory data-collection systems without requiring a direct client connection.

## No Microwave Excitation

The firmware supports all-optical quenching sensing only. Full ODMR (Optically Detected Magnetic Resonance) requires integration of a microwave signal source, frequency sweep control, and lock-in or synchronous detection. The existing IIR filtering and dip-detection architecture is compatible with this extension; only the hardware excitation layer and synchronisation logic would need to be added.

## ADS1015 for Higher Acquisition Rate

The ADS1015 (12-bit) offers conversion rates up to 3300 SPS versus 860 SPS for the ADS1115. For applications requiring finer temporal resolution of fast rotation, the ADS1015 is a pin-compatible replacement. The firmware would require CONV_PERIOD_US to be updated to 304 µs and the gain selection revisited for the reduced dynamic range.

# Appendix A — Source File Layout

PlatformIO project structure

ESP32S3_ReadOut_Web_Server/

├── platformio.ini

└── src/

├── main.cpp — acquisition loop, decimation, dip latch

├── nv_signal.h — NvSample, NvConfig, public API

├── nv_signal.cpp — ADC, dual IIR filters, baseline, dip detection, RPM

├── csv_logger.h — csv_push(), csv_write_to_client() declarations

├── csv_logger.cpp — 2000-entry circular buffer, HTTP CSV streaming

├── web_ui.h — web_init(), web_loop(), web_publish_sample()

├── web_ui.cpp — Wi-Fi AP, HTTP routes, WebSocket server

├── web_page.h — INDEX_HTML PROGMEM declaration

└── web_page.cpp — complete browser application as C string literal

# Appendix B — WebSocket JSON Protocol

## Server → Client — Sample Frame

Broadcast to all connected clients at ~22 Hz. Field t is milliseconds from ESP32 boot; delta is in raw ADC counts; dip is 1 on the frame where a quench event is confirmed, 0 otherwise.

Sample frame (broadcast at ~22 Hz)

{ "t": 45231,

"raw": 18432.5,

"filtered": 18431.1,

"delta": -42.3,

"dip": 1,

"rpm": 61.5

}

## Client → Server — Configuration Update

Sent by the browser on pressing Apply Settings. All three fields must be present.

Configuration message

{ "type": "cfg",

"alpha": 0.05,

"avg": 10,

"thr": -45.0

}

## Server → Client — Configuration Acknowledgement

Sent only to the requesting client. Values reflect the result of nv_set_config() clamping — the browser updates its sliders to match.

Acknowledgement (unicast to requesting client)

{ "type": "cfg_ack",

"alpha": 0.050,

"avg": 10,

"thr": -45.00

}

## Server → All Clients — Recalibration Notification

Broadcast by the server after a successful /recal HTTP request or a WebSocket recal command. All connected browsers flash the Recalibrate button green on receipt.

Recalibration notification (broadcast)

{ "type": "recal_done" }

Firmware & Software Documentation

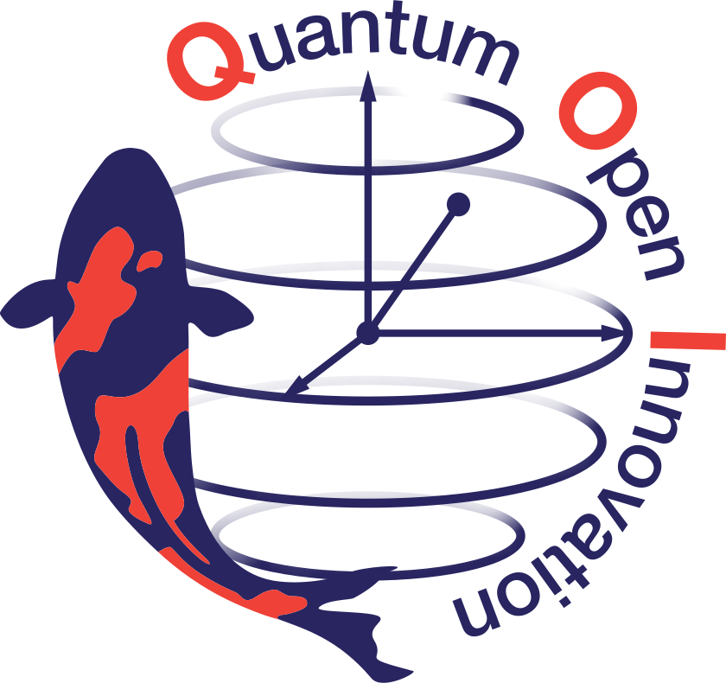
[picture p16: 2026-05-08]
Design/Photos/82d01a97-71ed-4804-91bd-9032aadffd37.png

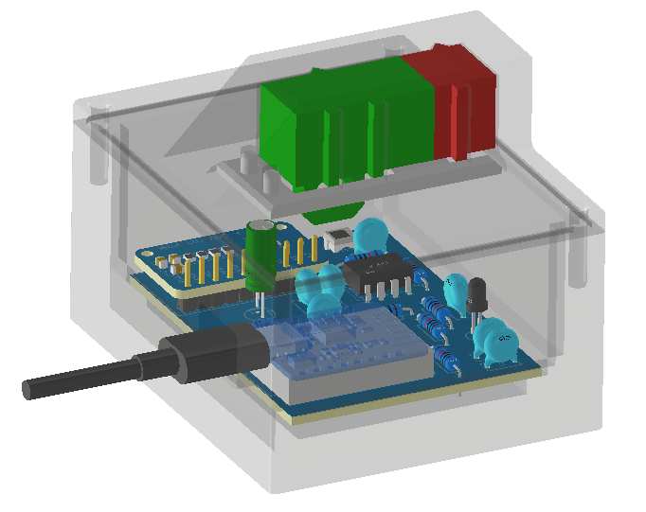
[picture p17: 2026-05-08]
Design/Design Photos/NV_Box_internals.png

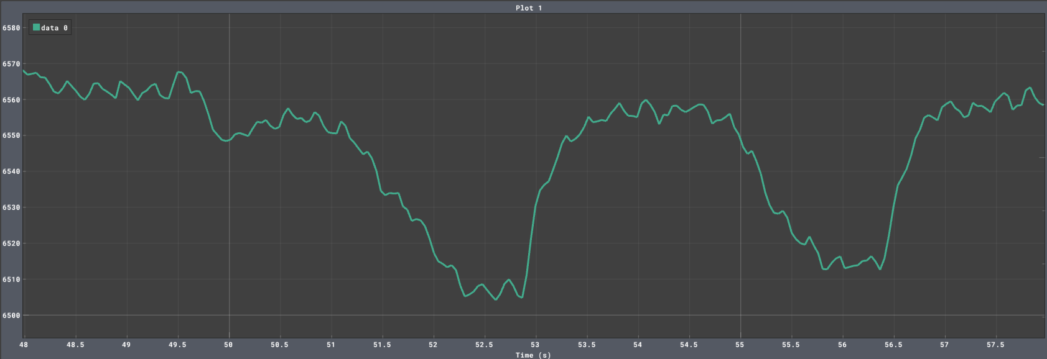
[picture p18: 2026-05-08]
Design/Design Photos/Second Design plot.png

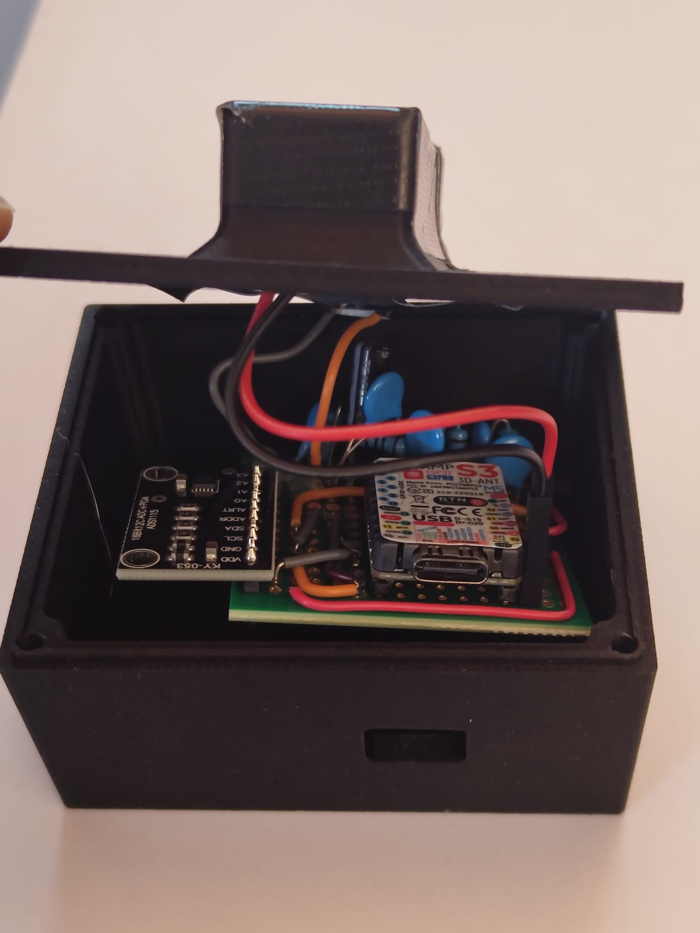
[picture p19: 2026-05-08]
Design/Design Photos/WhatsApp Image 2025-12-04 at 10.32.10_ab44e2be.jpg

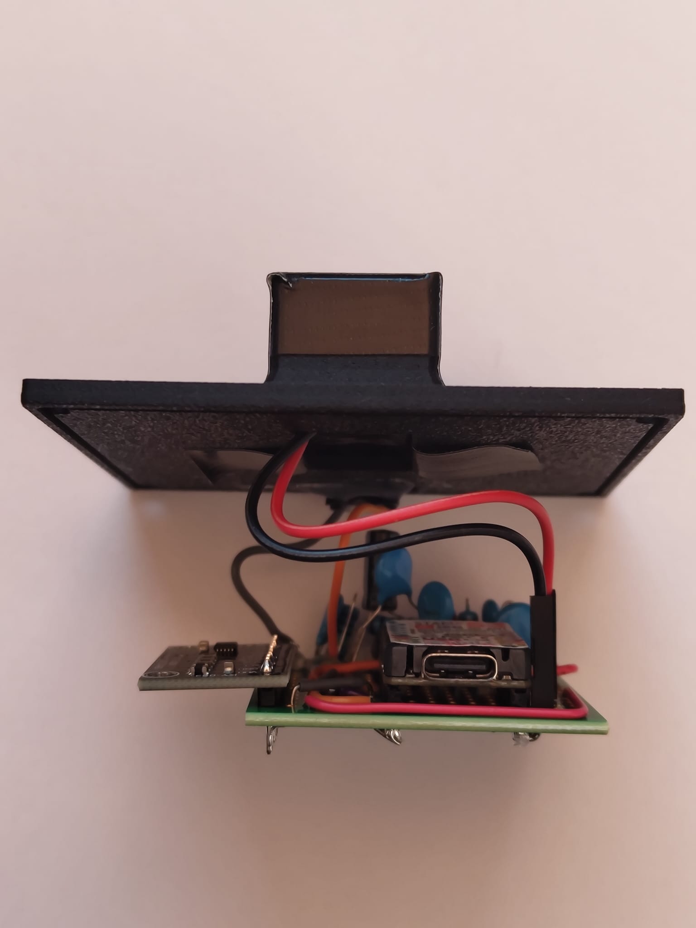
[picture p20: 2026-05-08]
Design/Design Photos/WhatsApp Image 2025-12-04 at 10.32.10_fce3376e.jpg

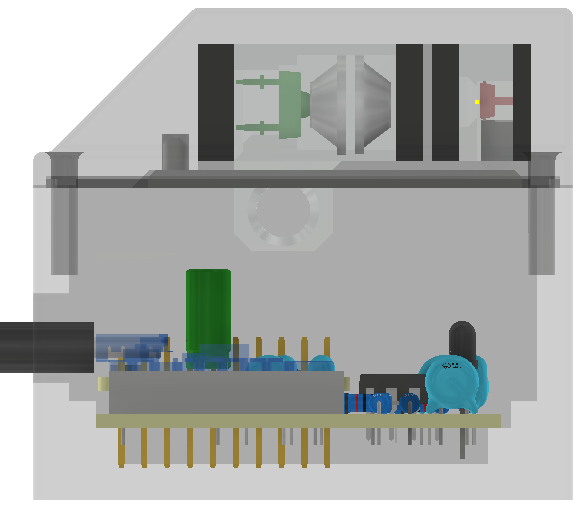
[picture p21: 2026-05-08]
Design/Design Photos/NV_Box_side_view.png

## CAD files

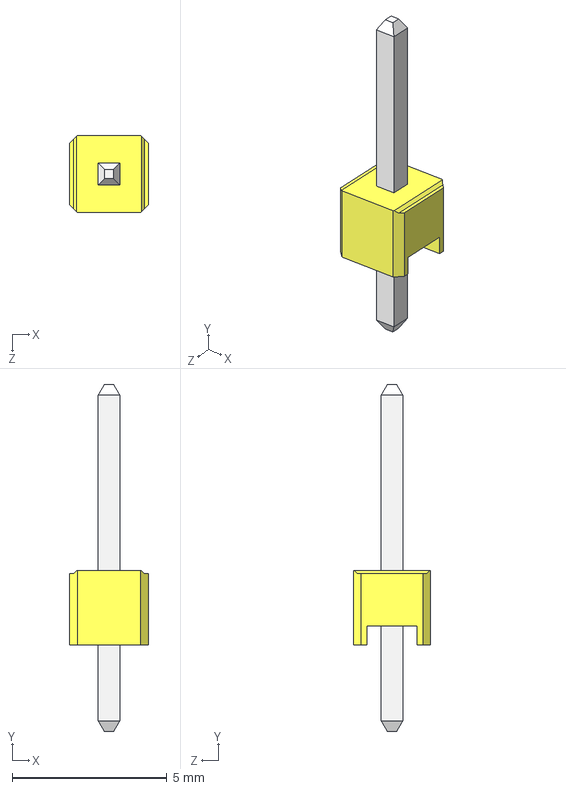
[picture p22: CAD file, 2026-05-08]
Design/Parts/2-54mm-male-pin-header-1.snapshot.3/Step/100mill Male Pin Header_1P_Y.STEP
2.54 x 11.2 x 2.50 mm

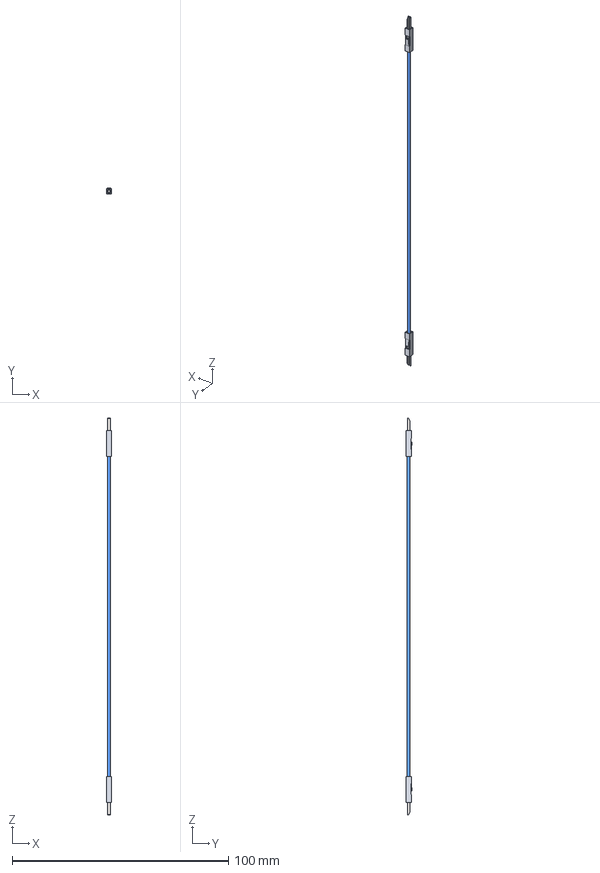
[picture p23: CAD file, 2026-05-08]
Design/Parts/dupont-jumper-wire-1.snapshot.3/Dupont Jumper Wire M-M.step
2.54 x 2.79 x 183.6 mm
DS1071-1x1 x 2

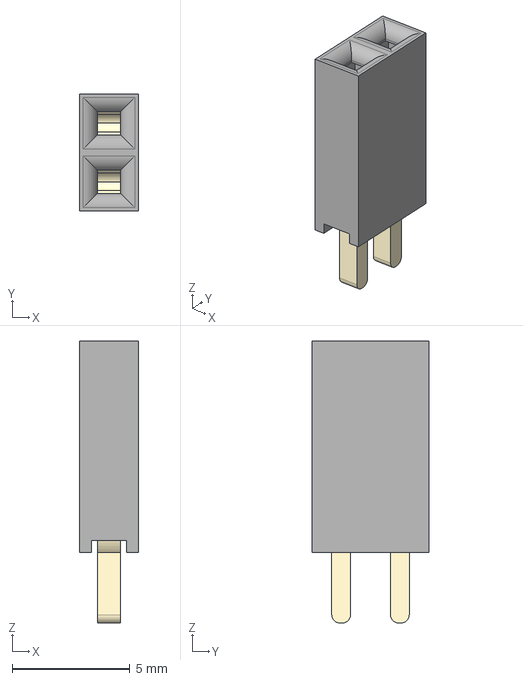
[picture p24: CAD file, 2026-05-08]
Design/Parts/female-header-pins-2.snapshot.2/Female 2 Pin Header.step
2.50 x 5.00 x 12.0 mm

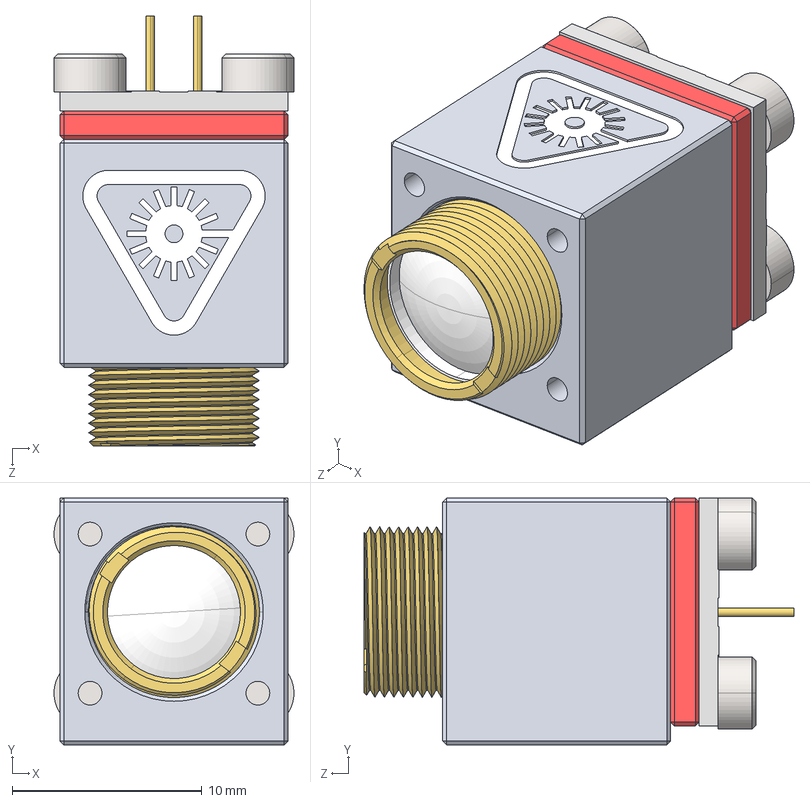
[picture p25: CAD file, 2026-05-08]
Design/Parts/Laser Diode Mounting Block.STEP
12.6 x 13.0 x 22.6 mm
Laser Diode Mount_Red
Nichia NUBM07E 465nm Laser Diode
Mounting Block Back Plate_Red
LD module tension spring
G-2 lens focusable mount
G-2 colimating lens
Soldering Board PCB
socket head cap screw_am_B18.3.1M - 2 x 0.4 x 6 Hex SHCS -- 6NHX x 4

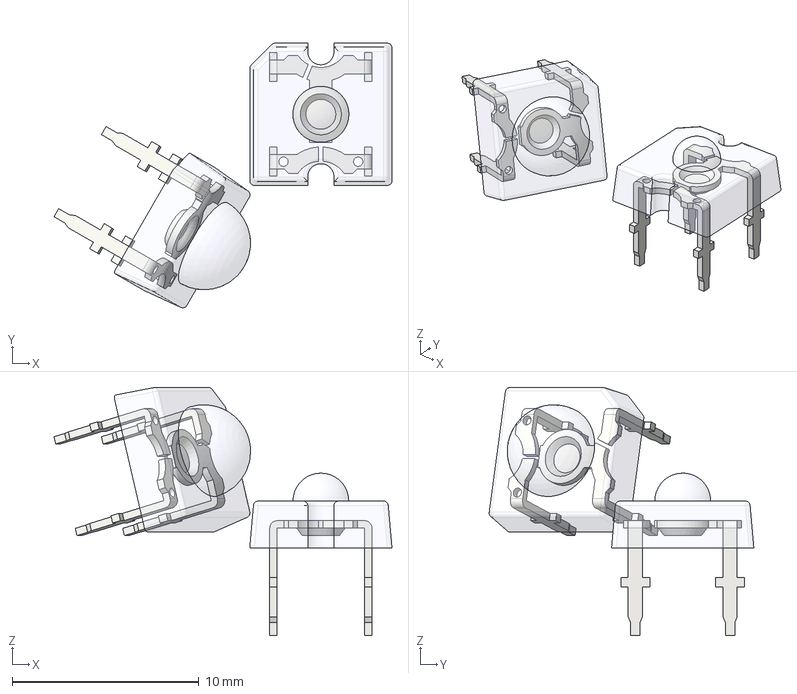
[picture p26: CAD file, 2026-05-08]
Design/Parts/led-s-piranha-super-flux-rgb-for-kicad-1.snapshot.11/LED-PiranhaSuperFlux.native3d/Piranha SuperFlux.FCStd
18.1 x 14.2 x 13.3 mm
Pin FOUR001
Pin TWO001
Pin THREE001
Pin ONE001
Epoxy Casing001
Pin FOUR003
Pin TWO003
Pin THREE003
Pin ONE003
Epoxy Casing003

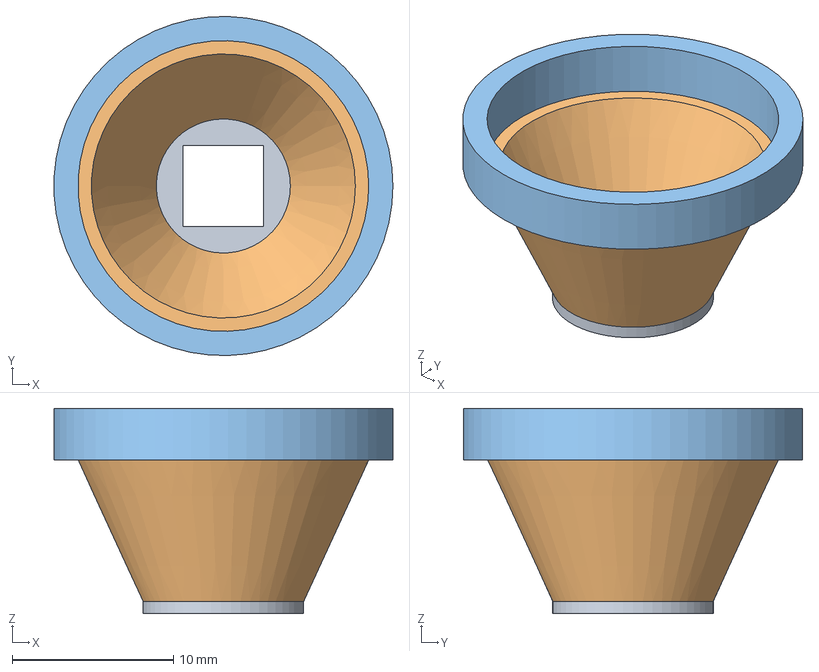
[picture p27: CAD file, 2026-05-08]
Design/Parts/xml2-xhp50-lens-2.snapshot.2/LEN-R.stp
21.0 x 21.0 x 12.7 mm
Base.Body
C獼e.Body
Surface.Body

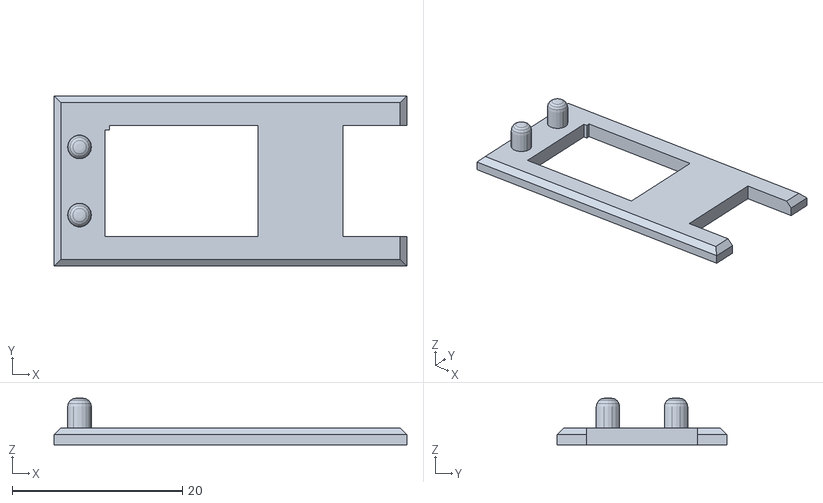
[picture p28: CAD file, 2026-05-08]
Design/Print/Modules_cover.stl
41.5 x 20.0 x 5.50

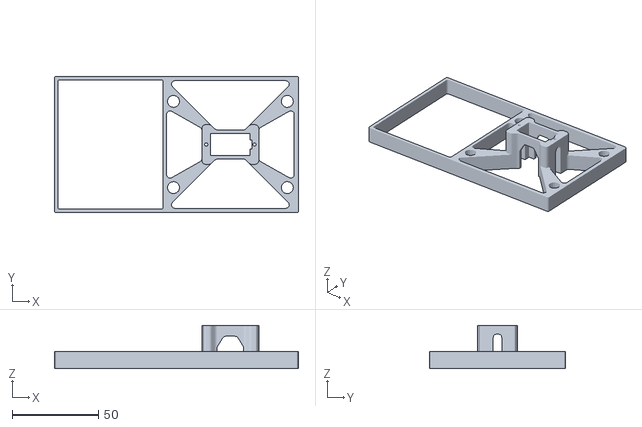
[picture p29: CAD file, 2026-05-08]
Design/Servo_magnet.stl
141.5 x 79.0 x 25.0

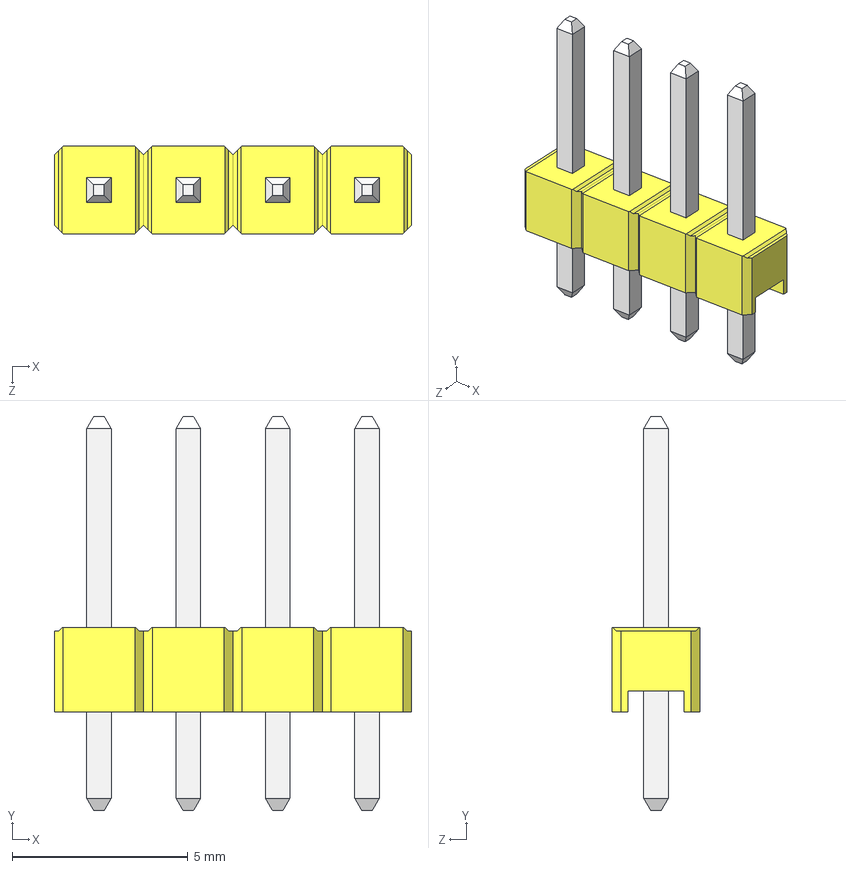
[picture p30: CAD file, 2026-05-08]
Design/Parts/2-54mm-male-pin-header-1.snapshot.3/Step/100mill Male Pin Header_4P_Y.STEP
10.2 x 11.2 x 2.50 mm

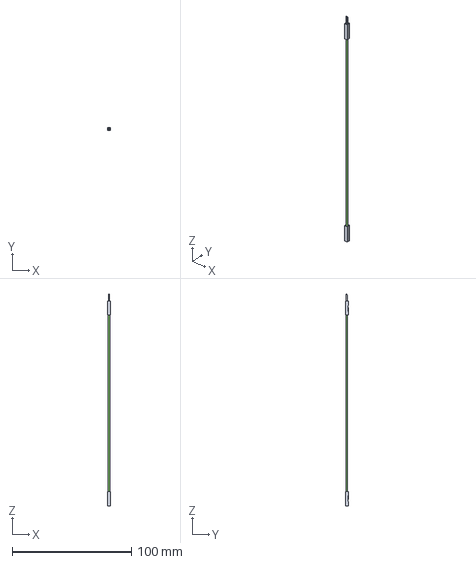
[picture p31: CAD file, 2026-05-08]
Design/Parts/dupont-jumper-wire-1.snapshot.3/Dupont Jumper Wire F-M.step
2.54 x 2.79 x 177.8 mm
DS1071-1x1
DS1071-1x1_1

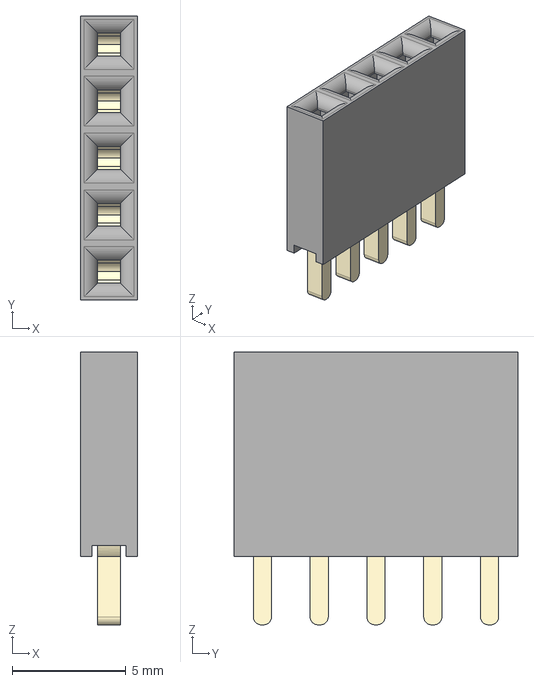
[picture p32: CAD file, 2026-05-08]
Design/Parts/female-header-pins-2.snapshot.2/Female 5 Pin Header.step
2.50 x 12.5 x 12.0 mm

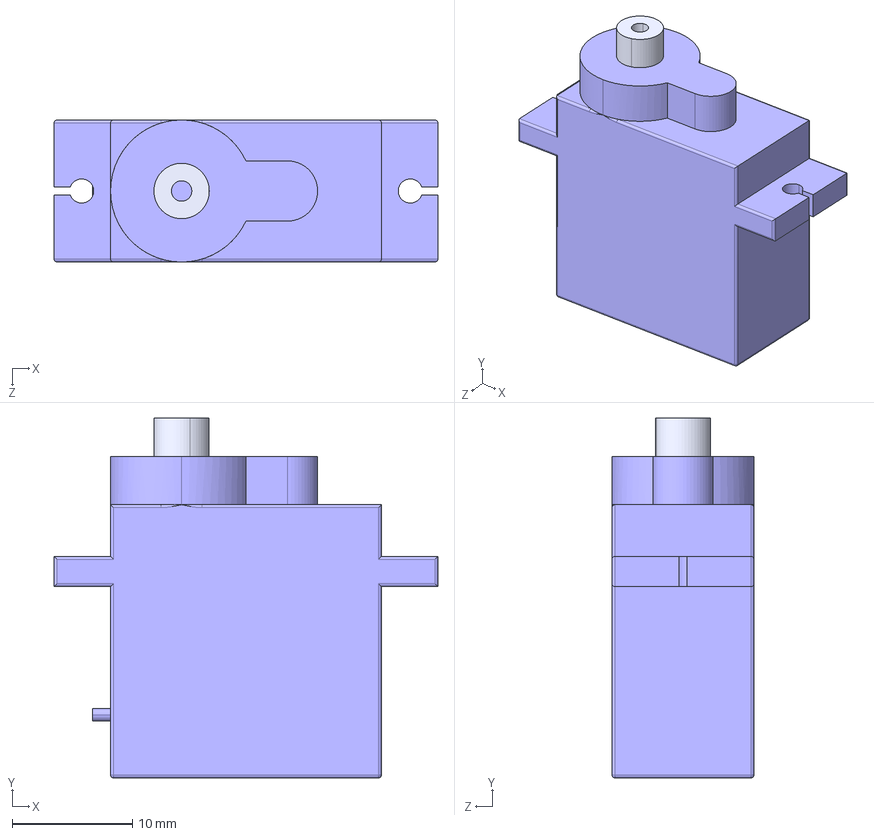
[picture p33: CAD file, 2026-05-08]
Design/Parts/sg90 micro servo.STEP
31.9 x 29.9 x 11.8 mm
axis.step

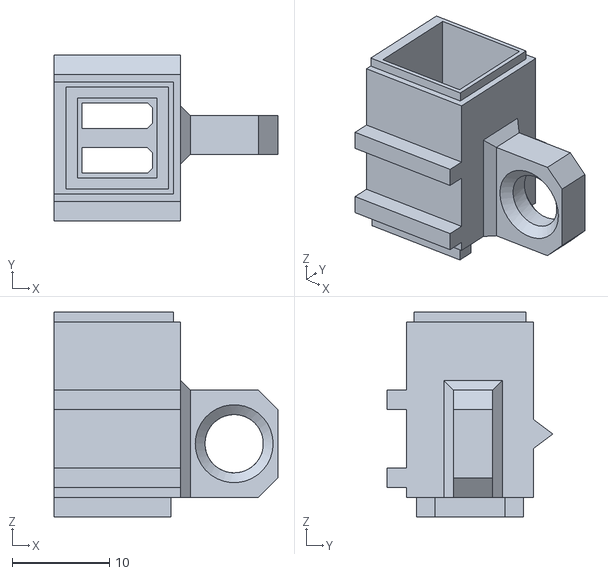
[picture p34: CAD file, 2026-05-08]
Design/Print/Optical module.stl
23.0 x 17.0 x 21.0

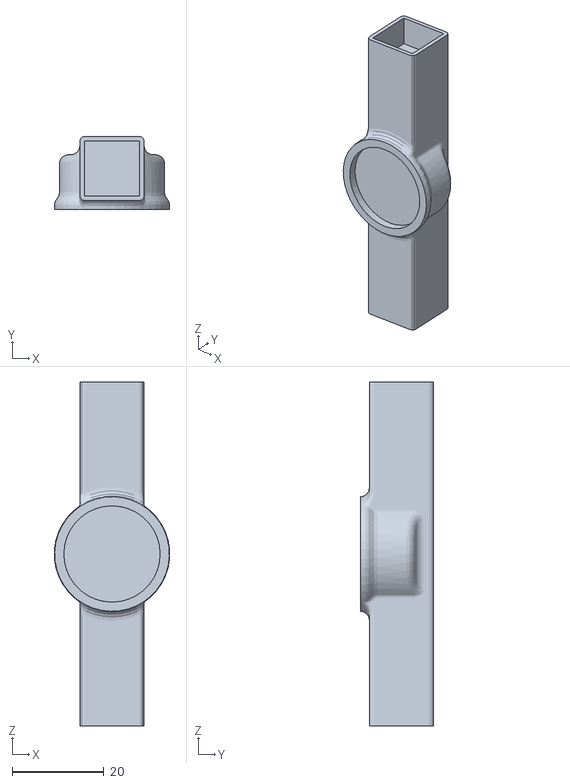
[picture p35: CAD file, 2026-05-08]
Design/Servo_holder.stl
25.1 x 16.0 x 75.0

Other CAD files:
Design/Parts/xml2-xhp50-lens-2.snapshot.2/reflector.FCStd
Design/koi.stl
Design/Parts/2-54mm-male-pin-header-1.snapshot.3/Step/100mill Male Pin Header_8P_Y.STEP
Design/Parts/bpw34.STEP
Design/Assembly_Box.iam
Design/Assembly_NV_Module.iam
Design/Assembly_NV__Optical_Modules.iam
Design/Assembly_Optical_Module.iam
Design/Assembly_Quenching.iam
Design/Assembly_Servo.iam
Design/Assembly_box_kit.iam
Design/Box_bottom_v2.ipt
Design/Box_lid_v4.ipt
Design/ImageToStl.com_82d01a97-71ed-4804-91bd-9032aadffd37.stl
Design/Modules_cover.ipt
Design/NV_module.ipt
Design/NV_module_lid_2.ipt
Design/Optical module.ipt
Design/Optical module_lid.ipt
Design/Optical module_lid_2.ipt
Design/Optical module_lid_v2.ipt
Design/Parts/2-54mm-male-pin-header-1.snapshot.3/Step/100mill Male Pin Header_10P_Bk.STEP
Design/Parts/2-54mm-male-pin-header-1.snapshot.3/Step/100mill Male Pin Header_10P_Y.STEP
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

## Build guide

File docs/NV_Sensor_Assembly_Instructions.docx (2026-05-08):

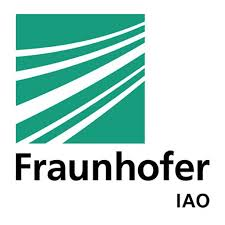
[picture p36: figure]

| | Quantum Open Innovations | ASSEMBLY INSTRUCTIONS NV-Diamond Quantum Sensor · Rev 1.0

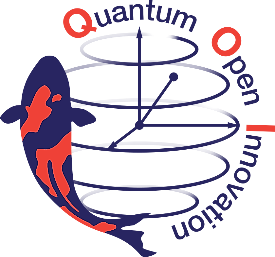
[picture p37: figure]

NV-Diamond Quantum Sensor

Fluorescence Quenching Readout Prototype

⏱ ~15 min assembly 8 steps No soldering

PARTS INCLUDED

A 1× Main PCB | B 1× 16-bit I²C ADC Module | C 1× STAMP M5 ESP32 | D 1× Bottom Enclosure | E 1× Top Lid | F 1× Optical Module | G 1× Sensor Module | H 1× USB-C Cable & Power bank | I 4× M3 Screws

ASSEMBLY STEPS

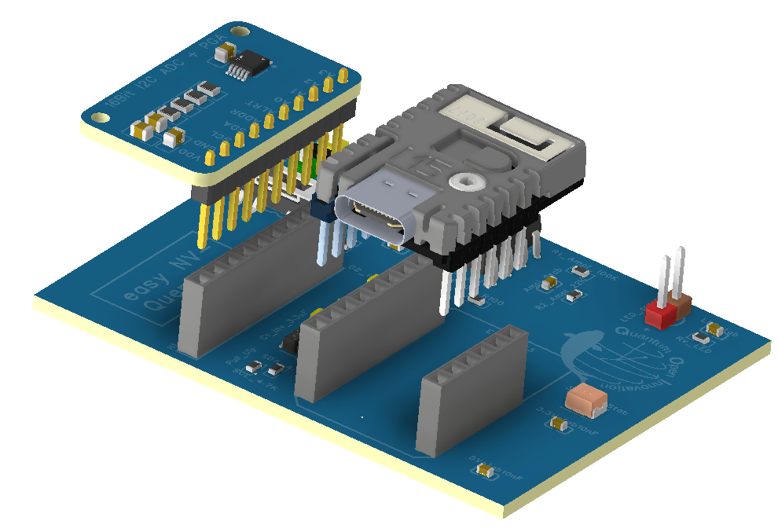
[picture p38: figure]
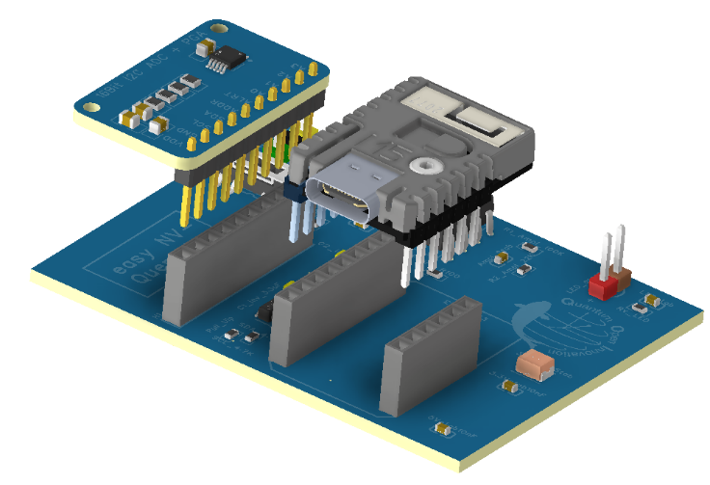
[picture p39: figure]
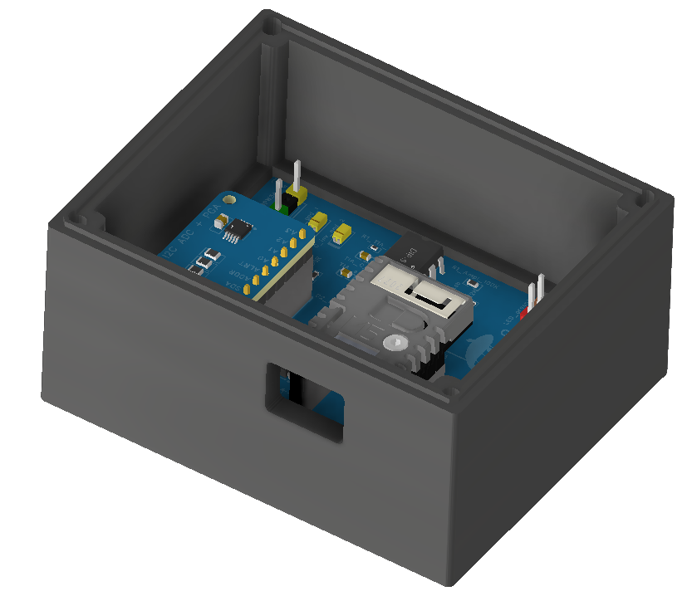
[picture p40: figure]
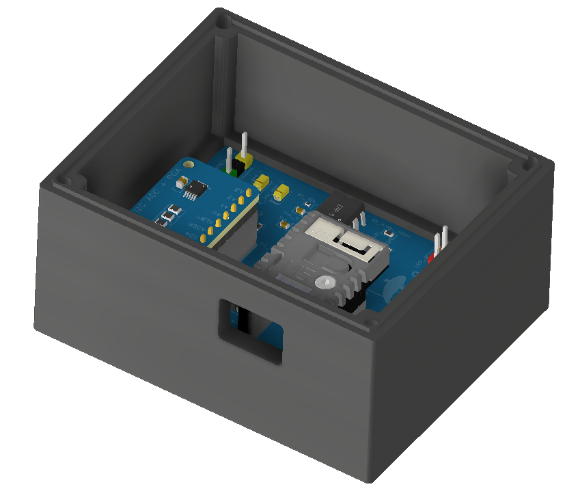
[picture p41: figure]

1 Mount PCB modules B C A Mount the 16-bit ADC Module (B) onto the Main PCB (A). Then place the STAMP-M5 ESP32 (C) into its socket. Press each firmly until pins are fully engaged and boards sit flush. Align pin markers before pressing. No gap should be visible. | 2 Place PCB into enclosure D Lower the assembled PCB into the Bottom Enclosure (D). The USB-C port must face the front cutout. Press down until the board sits flat on mounting posts. USB-C port alignment is critical. Verify from the front opening before continuing.

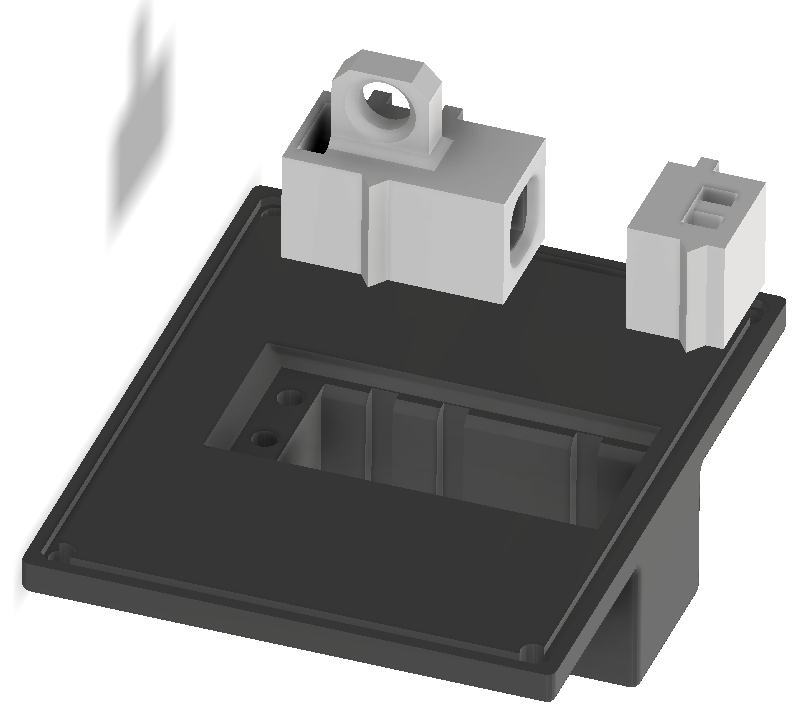
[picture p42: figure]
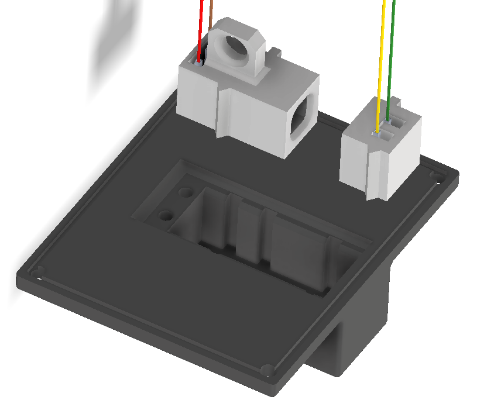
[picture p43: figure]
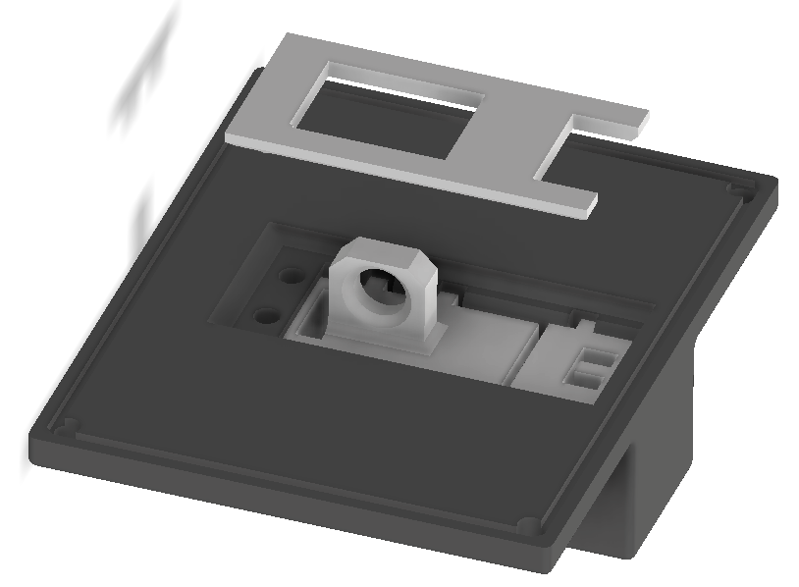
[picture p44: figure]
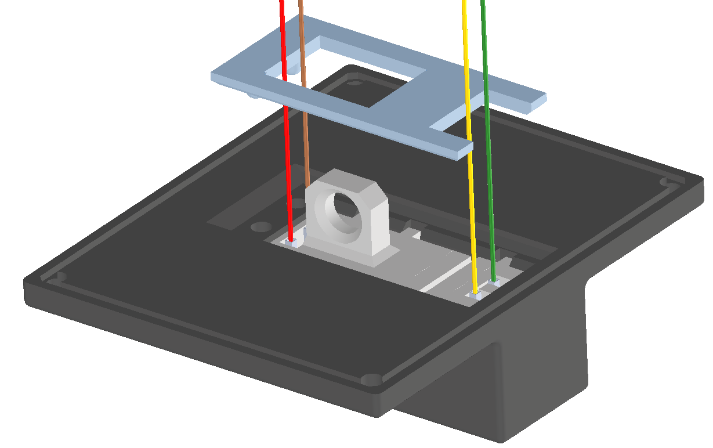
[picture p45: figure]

3 Prepare the top lid F E G Insert the Optical Module (F) into the left opening of the Top Lid (E). Insert the Sensor Module (G) into the right slot. Both mount from the inner face. The connector is keyed — one way only. If it resists, rotate 180° and try again. Never force. | 4 Seat lid components Press both modules fully into their slots until they sit flush with the interior surface. No part should protrude inward.

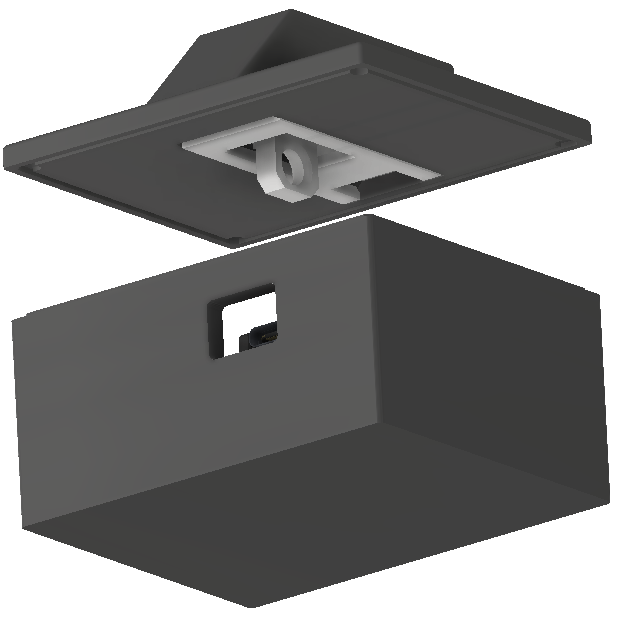
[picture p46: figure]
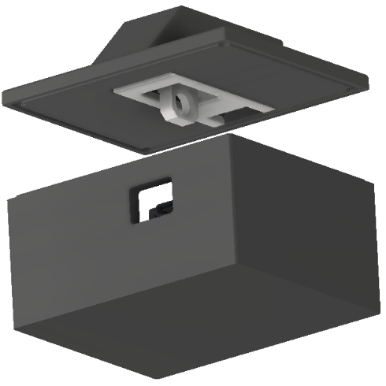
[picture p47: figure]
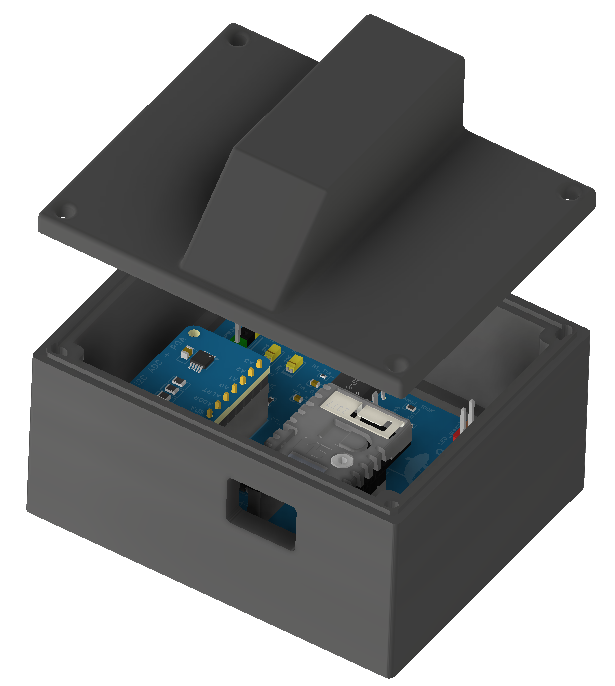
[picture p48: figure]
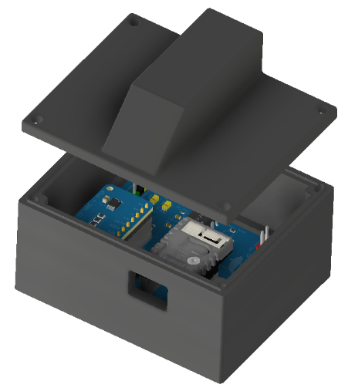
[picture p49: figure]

6 Verify before closing Verify both sub-assemblies match the image. The enclosure holds the PCB stack flat; the lid has both modules flush mounted. Nothing should move from either half. ✅ Checklist: ADC board seated · ESP32 seated · USB-C port visible at front · lid modules flush · Wires connected | 7 Align the lid Hold the Top Lid (E) directly above the enclosure. Align corner screw holes with the enclosure posts. Lid connector pins must line up with the PCB headers before lowering. Use the 4x M3 Screws (I) to seal the box. Lower straight down as shown in the image. Hand tight the screws, do not apply too much force.

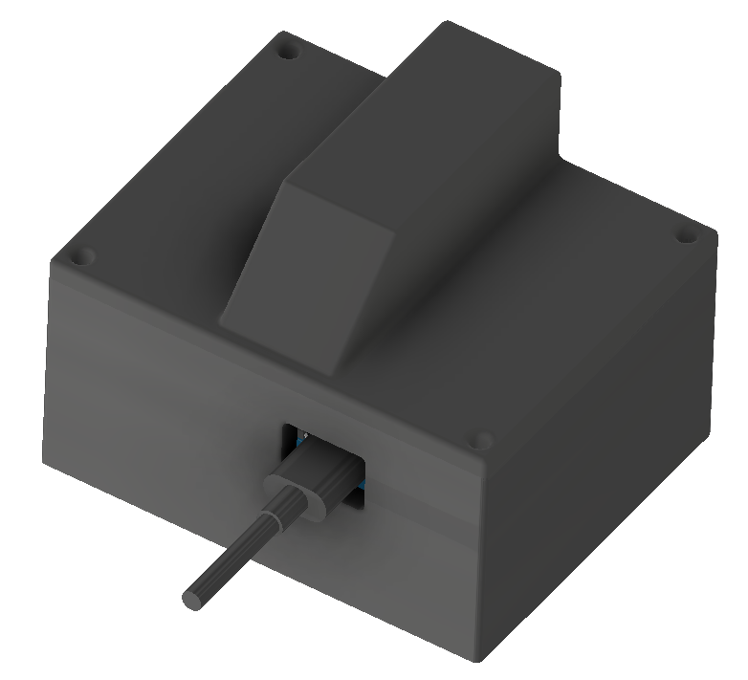
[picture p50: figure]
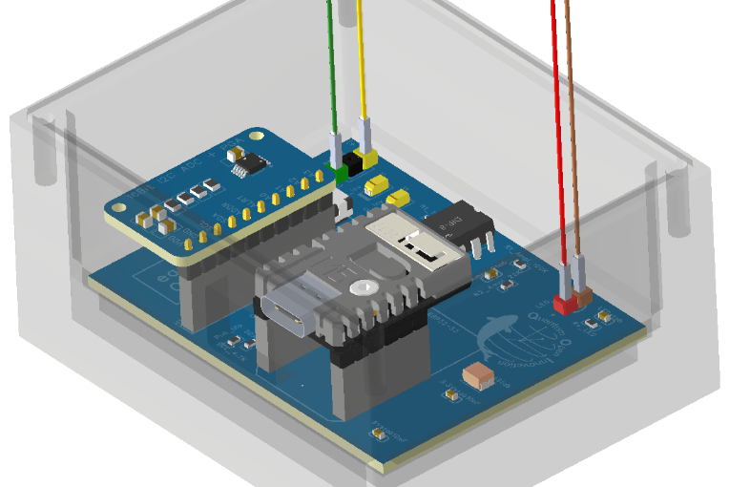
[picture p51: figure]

5 Connect color-coded wires to PCB With the lid partially lowered, connect the four wires from the lid connector to the matching PCB header pins. Match by color before fully seating the lid. ⚠️ Reversing Red and Brown wires can damage the LED. Always verify wire colors against PCB silkscreen labels before fully lowering the lid.

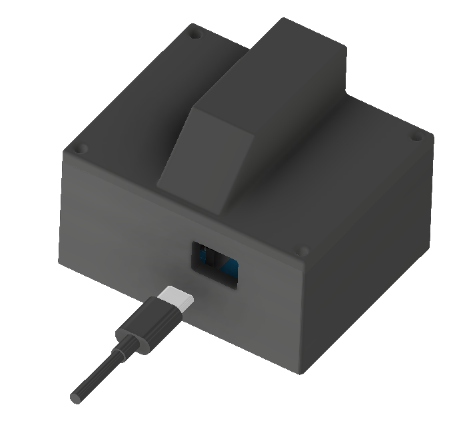
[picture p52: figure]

H | 8 Connect USB-C & power on Connect the USB-C cable (H) between the front port and Power bank. The device powers on immediately. The LED glows green within seconds as the NV-Plotter Wi-Fi hotspot initializes. 🎉 Assembly complete! If LED does not light, unplug, reopen and verify all header pins are fully seated (step 5). Next step → Connect to the sensor's Wi-Fi hotspot and open the browser dashboard for live fluorescence data.

FIRST CONNECTION Connect to the sensor's Wi-Fi hotspot Once powered, the NV sensor broadcasts its own access point. Connect any phone or laptop - no app, no driver, no cloud needed. Open a browser to see the live fluorescence waveform, dip event log, and one-click CSV export. Sensitivity is tunable in real time from the browser. | 📶NV-Plotter-(N) Password: 12345678 Browser → 192.168.10.1 iOS · Android · Windows · macOS

Fraunhofer IAO Quantum Open Innovations · Stuttgart · 2026 | NV-Diamond Quantum Sensor ·Assembly Instructions · Rev 1.0

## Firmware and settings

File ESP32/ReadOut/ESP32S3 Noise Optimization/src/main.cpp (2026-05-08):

#include <Arduino.h>
#include <Wire.h>
#include <Adafruit_ADS1X15.h>

Adafruit_ADS1115 ads;

// ---------- CONFIGURACIÓN ----------
//const int espAdcPin = 36;         // GPIO 36 (ESP WROOM 32)
const int espAdcPin = 5;            // GPIO 5 (STAMP S3)
const float VadcEsp = 2.65;         // Rango real ADC interno
const int ADCmaxEsp = 4095;

const float VadcADS = 4.096;        // Rango PGA ADS1115 (GAIN_ONE) 4.096 v
const int N = 4;                    // Promedio puntual
const int windowSize = 500;         // Ventana para cálculo de ruido
const uint32_t sampleInterval = 2000; // µs → 500 Hz aprox
// -----------------------------------

uint32_t lastSample = 0;

// Buffers circulares para mantener últimas lecturas
float bufferADS[windowSize];
float bufferESP[windowSize];
int idx = 0;
bool filled = false;

void setup() {
  Serial.begin(115200);
  delay(800);

  // --- ADC interno ---
  analogReadResolution(12);
  analogSetAttenuation(ADC_11db);

  // --- ADS1115 ---
  Wire.begin(13, 15);         //(21, 22); // SDA, SCL para WROOM32
  if (!ads.begin(0x48)) {
    Serial.println("❌ No se detecta el ADS1115");
    while (true) delay(100);
  }
  //ads.setGain(GAIN_ONE);
  //ads.setDataRate(RATE_ADS1115_860SPS);

  ads.setGain(GAIN_FOUR);                // ±2.048 V  → 62.5 µV/LSB
  ads.setDataRate(RATE_ADS1115_128SPS); // menos ruido, banda suficiente


  Serial.println("=== Comparación de ruido continua: ADS1115 vs ADC interno ===");
  Serial.println("sample,adsV,espV,noiseADS_mV,noiseESP_mV");
}

void loop() {
  if (micros() - lastSample >= sampleInterval) {
    lastSample += sampleInterval;

    // --- ADS1115 ---
    long tmpADS = 0;
    for (int i = 0; i < N; i++) {
      tmpADS += ads.readADC_SingleEnded(0);
      delayMicroseconds(100);
    }
    float rawADS = tmpADS / (float)N;
    float vADS = (rawADS / 32768.0f) * VadcADS;

    // --- ADC interno ---
    long tmpESP = 0;
    for (int i = 0; i < N; i++) {
      tmpESP += analogRead(espAdcPin);
      delayMicroseconds(50);
    }
    float rawESP = tmpESP / (float)N;
    float vESP = (rawESP / (float)ADCmaxEsp) * VadcEsp;

    // --- Guarda las nuevas lecturas en el buffer circular ---
    bufferADS[idx] = vADS;
    bufferESP[idx] = vESP;
    idx = (idx + 1) % windowSize;
    if (idx == 0) filled = true;

    // --- Calcula ruido actual usando la ventana disponible ---
    int n = filled ? windowSize : idx;
    double sumADS = 0, sumESP = 0, sumSqADS = 0, sumSqESP = 0;
    for (int i = 0; i < n; i++) {
      sumADS += bufferADS[i];
      sumESP += bufferESP[i];
      sumSqADS += bufferADS[i] * bufferADS[i];
      sumSqESP += bufferESP[i] * bufferESP[i];
    }
    double meanADS = sumADS / n;
    double meanESP = sumESP / n;
    double varADS = (sumSqADS / n) - (meanADS * meanADS);
    double varESP = (sumSqESP / n) - (meanESP * meanESP);
    double noiseADS = sqrt(varADS) * 1000.0; // mV RMS
    double noiseESP = sqrt(varESP) * 1000.0; // mV RMS

    // --- Muestra resultados en CSV ---
    Serial.printf("vADS: %.6f\n", vADS);
  }
}

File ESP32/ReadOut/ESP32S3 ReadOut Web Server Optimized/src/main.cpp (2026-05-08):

/**
 * main.cpp — Application entry point for the NV Quenching Plotter
 *
 * This firmware runs on an ESP32 and performs the following tasks in a
 * cooperative loop:
 *   1. Reads and filters ADC samples from an ADS1115 (via nv_signal).
 *   2. Detects "dip" events (drops in signal below a configurable threshold).
 *   3. Pushes decimated samples to a circular CSV log buffer.
 *   4. Broadcasts live data to connected browser clients over WebSocket.
 *
 * Hardware connections (I²C):
 *   SDA → GPIO 13
 *   SCL → GPIO 15
 */

#include <Arduino.h>
#include <Wire.h>
#include "nv_signal.h"
#include "web_ui.h"
#include "csv_logger.h"

// ── Decimation ────────────────────────────────────────────────────────────────
// nv_step() is called every loop iteration (potentially several hundred Hz),
// but the web UI and CSV buffer only receive every Nth sample.
// Reducing this reduces bandwidth and CPU; raising it increases data density.
static const uint8_t SEND_EVERY_N = 4;

// Running sample counter used for modulo-based decimation.
static uint32_t counter = 0;

// ── Dip accumulation across decimation window ─────────────────────────────────
// If a dip fires on any of the N raw samples between published outputs, this
// flag is set so the dip is NOT silently dropped by the decimation step.
static bool dipPending = false;

void setup() {
  Serial.begin(115200);
  delay(200);  // Allow USB serial to stabilise before first prints

  // Initialise I²C bus on non-default pins required by the PCB layout.
  Wire.begin(13, 15);

  // Initialise the ADS1115 ADC, set gain/data-rate, and capture the signal
  // baseline. Halts with an error message if the chip is not found.
  if (!nv_init()) {
    Serial.println("ADS1115 not found!");
    while (true) delay(200);  // Blink-of-death; sensor is required
  }

  // Start the WiFi AP, HTTP server, and WebSocket server.
  web_init();
}

void loop() {
  // Service any pending HTTP requests and WebSocket frames from connected
  // clients. Must be called frequently to avoid client timeouts.
  web_loop();

  // Read samplesToAvg fresh ADC conversions, apply IIR filtering, and run
  // dip-detection logic. Returns a fully populated NvSample struct.
  NvSample s = nv_step();

  // Latch any dip that fires inside the current decimation window so it is
  // still reported even if this particular raw sample did not carry it.
  if (s.dip) dipPending = true;

  if (++counter % SEND_EVERY_N == 0) {
    // Stamp the accumulated dip flag onto the outgoing (decimated) sample,
    // then clear it ready for the next decimation window.
    s.dip    = dipPending;
    dipPending = false;

    // Append to the circular CSV ring buffer (oldest entry is overwritten
    // once the buffer is full — see csv_logger.cpp).
    csv_push(s);

    // Broadcast a compact JSON message to all connected WebSocket clients.
    web_publish_sample(s.raw, s.filtered, s.delta, s.dip, s.rpm);
  }
}

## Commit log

2026-05-08 Initial commit: NV-center readout system
    [100mill Male Pin Header_10P_Bk.STEP, 100mill Male Pin Header_10P_Y.STEP, 100mill Male Pin Header_10P_Y.ipt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]
2026-05-08 fix: add missing directory entries for Ordered PCB in .gitignore
2026-05-08 fix: remove obsolete invoice file from Ordered PCB directory
2026-05-08 Add assembly instructions, firmware documentation, and quick reference for NV-Diamond Quantum Sensor
    - Created NV_Sensor_Assembly_Instructions.docx detailing assembly steps and components for the NV-Diamond Quantum Sensor.
    - Added NV_Supplement.docx providing comprehensive firmware and software documentation, including system architecture, signal processing, and performance metrics.
    - Introduced NV_quick_reference.docx summarizing key specifications, configuration parameters, and system performance for quick access.
2026-05-08 Remove outdated schematic and project files from the repository, including NV Quenching and Samuel Quenching projects, as well as associated backups and documentation. This cleanup helps maintain a m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
    [ADS1115.kicad_pcb, ADS1115.kicad_sch, BOM_Quenching_kit_PCB5_2026-02-13.xlsx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]
2026-05-21 Add assembly instructions PDF to documentation
2026-05-21 feat: update assembly walkthrough with new images for clearer instructions
2026-05-21 feat: enhance assembly walkthrough layout for improved clarity

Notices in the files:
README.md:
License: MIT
